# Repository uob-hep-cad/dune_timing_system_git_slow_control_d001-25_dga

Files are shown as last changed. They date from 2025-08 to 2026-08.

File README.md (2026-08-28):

# Design files for DUNE Timing System GIB Slow Control Board

### Current version: PCB_Health.v5 

### Files produced with KiCAD 10.0

Design information in hardware/KiCAD

David.Cussans@bristol.ac.uk , 9/June/26
 
Directory with Gerber artwork: Gerber.D001-25.DGA.V5 

Component placement (CSV and Gerber): PCB_Health.V5-all-pos.csv PCB_Health.V5-pnp_top.gbr PCB_Health.V5-pnp_bottom.gbr

BoM: PCB_Health.V5_BOM.xlsx . Version from Newbury: cleaned_full_bom_for_external_users.xlsx

4-layer board. FR4. 1.6mm  Newbury Electronics "PCB train" stack-up

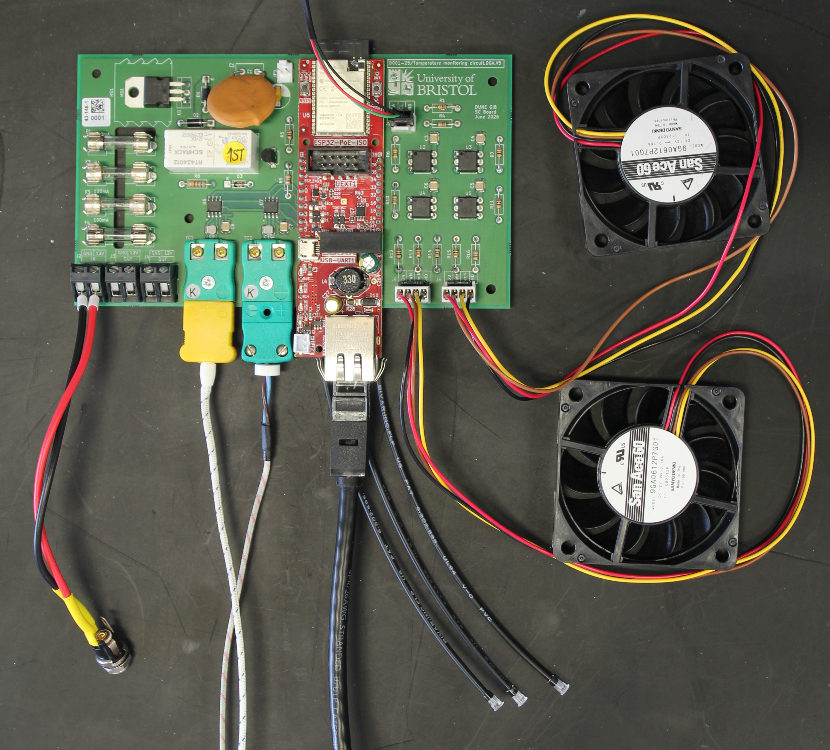
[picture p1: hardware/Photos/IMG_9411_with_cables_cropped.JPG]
photograph of assembled GIB slow control interface board
Photograph of assembled board:

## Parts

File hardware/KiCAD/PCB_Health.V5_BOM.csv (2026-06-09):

Reference | Qty | Value | DNP | Exclude from BOM | Exclude from Board | Footprint | Description | Datasheet
A1 | 1 | ESP32_POE |  |  |  | ESP32:ESP32-POE-ISO-WROVER | ESP32-POE-ISO-WROVER | https://cdn-learn.adafruit.com/downloads/pdf/adafruit-huzzah32-esp32-feather.pdf
C1 | 1 | 100n |  |  |  | Capacitor_THT:C_Disc_D9.0mm_W5.0mm_P5.00mm | Capacitor THT : C Disc D9.0mm W5.0mm P5.00mm 100n
C2 | 1 | 1u |  |  |  | Capacitor_THT:CP_Radial_D8.0mm_P5.00mm | Capacitor THT : CP Radial D8.0mm P5.00mm 1u
C3,C4,C5,C6,C7,C8 | 6 | 100n |  |  |  | Capacitor_SMD:C_1210_3225Metric | Capacitor SMD : C 1210 3225Metric 100n
C9,C10 | 2 | 10n |  |  |  | Capacitor_SMD:C_1210_3225Metric | Capacitor SMD : C 1210 3225Metric 10n
D1,D2 | 2 | 1N4001 |  |  |  | Diode_THT:D_DO-41_SOD81_P10.16mm_Horizontal | Diode THT : D DO-41 SOD81 P10.16mm Horizontal 1N4001 | http://www.vishay.com/docs/88503/1n4001.pdf
D3 | 1 | 1N4148 |  |  |  | Diode_THT:D_DO-35_SOD27_P7.62mm_Horizontal | Diode THT : D DO-35 SOD27 P7.62mm Horizontal 1N4148 | https://assets.nexperia.com/documents/data-sheet/1N4148_1N4448.pdf
D4,D5,D6 | 3 | LED |  |  |  | Library:FLPR60SG | FLPR60SG
F1 | 1 | 500mA |  |  |  | Library:Littelfuse 100 Spring Brass, PCB Fuse Clip for 5 x 20 mm Cartridge Fuse | Littelfuse 100 Spring Brass, PCB Fuse Clip for 5 x 20 mm Cartridge Fuse 500mA
F2 | 1 | 2A |  |  |  | Library:Littelfuse 100 Spring Brass, PCB Fuse Clip for 5 x 20 mm Cartridge Fuse | Littelfuse 100 Spring Brass, PCB Fuse Clip for 5 x 20 mm Cartridge Fuse 2A
F3,F4 | 2 | 100mA |  |  |  | Library:Littelfuse 100 Spring Brass, PCB Fuse Clip for 5 x 20 mm Cartridge Fuse | Littelfuse 100 Spring Brass, PCB Fuse Clip for 5 x 20 mm Cartridge Fuse 100mA
H1,H2,H4,H5 | 4 | MountingHole |  |  |  | MountingHole:MountingHole_3.2mm_M3 | MountingHole : MountingHole 3.2mm M3
HS1 | 1 | Heatsink |  |  |  | Heatsink:Heatsink_AAVID_TV5G_TO220_Horizontal | Heatsink : Heatsink AAVID TV5G TO220 Horizontal
J1 | 1 | Conn_01x03_Socket |  |  |  | Connector_PinHeader_2.54mm:PinHeader_1x03_P2.54mm_Vertical | Connector PinHeader 2.54mm : PinHeader 1x03 P2.54mm Vertical
J2,J3,J4 | 3 | Conn_01x02_Socket |  |  |  | TerminalBlock:TerminalBlock_Altech_AK300-2_P5.00mm | TerminalBlock : TerminalBlock Altech AK300-2 P5.00mm
J5 | 1 | Conn_01x04_Socket |  |  |  | Library:Mole_KK_1x04__Vertical | Molex KK 1x04 Vertical
J6 | 1 | Conn_01x04_Socket |  |  |  | Connector_PinHeader_2.54mm:PinHeader_1x04_P2.54mm_Vertical | Connector PinHeader 2.54mm : PinHeader 1x04 P2.54mm Vertical
JP1 | 1 | Jumper_2_Open |  |  |  | Connector_PinHeader_2.54mm:PinHeader_1x02_P2.54mm_Vertical | Connector PinHeader 2.54mm : PinHeader 1x02 P2.54mm Vertical
K1 | 1 | RT424012 |  |  |  | Relay_THT:Relay_DPDT_Schrack-RT2-FormC_RM5mm | Relay THT : Relay DPDT Schrack-RT2-FormC RM 5mm | http://www.te.com/commerce/DocumentDelivery/DDEController?Action=showdoc
Q1 | 1 | BC337 |  |  |  | Package_TO_SOT_THT:TO-92_Inline_Wide | Package TO SOT THT : TO-92 Inline Wide BC337 | https://diotec.com/tl_files/diotec/files/pdf/datasheets/bc337.pdf
R1,R4,R13,R15 | 4 | 10k |  |  |  | Library:R_Axial_DIN0207_L6.3mm_D2.5mm_P10.16mm_Horizontal | R Axial DIN0207 L6.3mm D2.5mm P10.16mm Horizontal 10k
R2 | 1 | 220 |  |  |  | Library:R_Axial_DIN0207_L6.3mm_D2.5mm_P10.16mm_Horizontal | R Axial DIN0207 L6.3mm D2.5mm P10.16mm Horizontal
R3 | 1 | 680 |  |  |  | Library:R_Axial_DIN0207_L6.3mm_D2.5mm_P10.16mm_Horizontal | R Axial DIN0207 L6.3mm D2.5mm P10.16mm Horizontal
R5,R7,R11,R12 | 4 | 270 |  |  |  | Library:R_Axial_DIN0207_L6.3mm_D2.5mm_P10.16mm_Horizontal | R Axial DIN0207 L6.3mm D2.5mm P10.16mm Horizontal
R6,R9,R10,R14,R16 | 5 | 470 |  |  |  | Library:R_Axial_DIN0207_L6.3mm_D2.5mm_P10.16mm_Horizontal | R Axial DIN0207 L6.3mm D2.5mm P10.16mm Horizontal
R8 | 1 | 620 |  |  |  | Library:R_Axial_DIN0207_L6.3mm_D2.5mm_P10.16mm_Horizontal | R Axial DIN0207 L6.3mm D2.5mm P10.16mm Horizontal
TC1,TC2 | 2 | Thermocouple_Alt |  |  |  | Connector Thermo:Thermocouple Connector | Connector Thermo : Thermocouple Connector
U1 | 1 | LM317_TO-220 |  |  |  | Package_TO_SOT_THT:TO-220-3_Vertical | Package TO SOT THT : TO-220-3 Vertical | http://www.ti.com/lit/ds/symlink/lm317.pdf
U2,U3,U4,U5 | 4 | H11L1 |  |  |  | Library:DIP-6_W7.62mm | DIP-6 W7.62mm | https://www.onsemi.com/pub/Collateral/H11L3M-D.PDF
U6,U7 | 2 | MAX6675ISA_ |  |  |  | MAX6675ISA_:SOIC127P600X175-8N | MAX6675ISA : SOIC127P600X175-8N

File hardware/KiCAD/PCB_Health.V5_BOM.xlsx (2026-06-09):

Description | Qty per BOM | Quantity per batch | Min Quantity to order | Manufacturer | Manufacturer Part Number | Supplier | Supplier Part Number | Designator | Package Type | Technology | Comment | Status | Original Manufacturer Part No from client BOM
ESP32-POE IOT EVAL BOARD | 1 | 2 | 2 | Olimex LTD | ESP32-POE-ISO-WROVER | DIGIKEY | 1188-ESP32-POE-ISO-WROVER-ND | A1 | Bulk | THT |  | Found | ESP32_POE
CAP CER 0.1UF 500V Z5V RADIAL | 7 | 14 | 14 | Vishay Beyschlag/Draloric/BC Components | S104Z93Z5VL83L0R | DIGIKEY | BC5183-ND | C1,C3,C4,C5,C6,C7,C8 | Bulk | THT |  | Found | 100n
CAP TANT 1UF 10% 25V RADIAL | 1 | 2 | 2 | KEMET | T356A105K025AT | DIGIKEY | 399-3603-ND | C2 | Bulk | THT |  | Found | 1u
YAGEO - CC1210FKNPO9BN103 - SMD Multilayer Ceramic Capacitor, 0.01 µF, 50 V, 1210 [3225 Metric], ± 1%, C0G / NP0 | 2 | 4 | 5 | YAGEO | CC1210FKNPO9BN103 | FARNELL | 4255887 | C9,C10 | Cut Tape | SMD |  | Found | 10n
MULTICOMP PRO - 1N4001. - DIODE, STANDARD RECOVERY, 1A, 50V, DO-204AL-2 | 2 | 4 | 5 | MULTICOMP PRO | 1N4001. | FARNELL | 2306346 | D1,D2 | Cut Tape | THT |  | Found | 1N4001
MULTICOMP PRO - 1N4148. - DIODE, ULTRAFAST RECOVERY, 150mA, 75V, DO-204AH-2 | 1 | 2 | 5 | MULTICOMP PRO | 1N4148. | FARNELL | 2306361 | D3 | Cut Tape | THT |  | Found | 1N4148
LED CBI 3MM GRN THROUGH HOLE | 3 | 6 | 6 | Bivar Inc. | FLPR6.0-SG | DIGIKEY | 492-1201-ND | D4,D5,D6 | Bag | THT |  | Found | LED
FUSE CLIP CARTRIDGE 250V 10A PCB | 1 | 2 | 2 | Littelfuse Inc. | 01000056Z | DIGIKEY | F3784-ND | F1 | Bulk | THT |  | Found | 500mA
FUSE CLIP CARTRIDGE 250V 10A PCB | 1 | 2 | 2 | Littelfuse Inc. | 01000056Z | DIGIKEY | F3784-ND | F2 | Bulk | THT |  | Found | 2A
FUSE CLIP CARTRIDGE 250V 10A PCB | 2 | 4 | 4 | Littelfuse Inc. | 01000056Z | DIGIKEY | F3784-ND | F3,F4 | Bulk | THT |  | Found | 100mA
BOYD - TV5G - Heat Sink, PCB, Board Level, 21.6 °C/W, TO-126, 22 mm, 19 mm, 19 mm | 1 | 2 | 2 | BOYD | TV5G | FARNELL | 170072 | HS1 | Each | UNMOUNTED |  | Found | Heatsink
Headers & Wire Housings 3C STR HEADER W/FRLK | 1 | 2 | 2 | Molex | 22-27-2031 | MOUSER | 538-22-27-2031 | J1 | Standard Pack Qty | THT |  | Found | Conn_01x03_Socket
Fixed Terminal Blocks AK300/2 PC 45DegGry | 3 | 6 | 6 | Altech | 30.602 | MOUSER | 845-30.602 | J2,J3,J4 | Standard Pack Qty | THT |  | Found | Conn_01x02_Socket
MOLEX - 171856-4004 - Pin Header, Black, Board-to-Board, Power, Signal, Wire-to-Board, 2.54 mm, 1 Rows, 4 Contacts | 2 | 4 | 4 | MOLEX | 171856-4004 | FARNELL | 4667772 | J5,J6 | Cut Tape | THT |  | Found | Conn_01x04_Socket
Conn Wire to Board HDR 2 POS 2.54mm Solder ST Top Entry Thru-Hole KK Bag | 1 | 2 | 2 | Molex | 0022232021 | ARROW | 0323_00039992 | JP1 | BAG | THT |  | Found | Jumper_2_Open
Power Relay 12VDC 8A DPDT(29x12.7x15.7)mm THT | 1 | 2 | 2 | TE Connectivity | RT424012 | ARROW | 0323_00028596 | K1 | BOX | THT |  | Found | RT424012
MULTICOMP PRO - BC337 - Bipolar (BJT) Single Transistor, NPN, 45 V, 800 mA, 625 mW, TO-92, Through Hole | 1 | 2 | 5 | MULTICOMP PRO | BC337 | FARNELL | 1574379 | Q1 | Each | THT |  | Found | BC337
MULTICOMP PRO - MCRE000049 - Through Hole Resistor, 10 kohm, MC CFR Series, 125 mW, ± 5%, Axial Leaded, 200 V | 4 | 8 | 8 | MULTICOMP PRO | MCRE000049 | FARNELL | 1700251 | R1,R4,R13,R15 | Each | THT |  | Found | 10k
MULTICOMP PRO - MCRE000029 - Through Hole Resistor, 220 ohm, MC CFR Series, 125 mW, ± 5%, Axial Leaded, 200 V | 1 | 2 | 5 | MULTICOMP PRO | MCRE000029 | FARNELL | 1700228 | R2 | Each | THT |  | Found | 220
MULTICOMP PRO - MCRE000035 - Through Hole Resistor, 680 ohm, MC CFR Series, 125 mW, ± 5%, Axial Leaded, 200 V | 1 | 2 | 5 | MULTICOMP PRO | MCRE000035 | FARNELL | 1700234 | R3 | Each | THT |  | Found | 680
MULTICOMP PRO - MCRE000030 - Through Hole Resistor, 270 ohm, MC CFR Series, 125 mW, ± 5%, Axial Leaded, 200 V | 4 | 8 | 8 | MULTICOMP PRO | MCRE000030 | FARNELL | 1700229 | R5,R7,R11,R12 | Each | THT |  | Found | 270
MULTICOMP PRO - MCRE000033 - Through Hole Resistor, 470 ohm, MC CFR Series, 125 mW, ± 5%, Axial Leaded, 200 V | 5 | 10 | 10 | MULTICOMP PRO | MCRE000033 | FARNELL | 1700232 | R6,R9,R10,R14,R16 | Each | THT |  | Found | 470
RES 620 OHM 5% 1/4W AXIAL | 1 | 2 | 2 | KOA Speer Electronics, Inc. | CF1/4CT52R621J | DIGIKEY | 2019-CF1/4CT52R621JCT-ND | R8 | Cut Tape (CT) | THT |  | Found | 620
LABFACILITY - IM-K-PCB - Thermocouple Connector, Miniature, Green, Socket, Type K, IEC, PCB Mount | 2 | 4 | 4 | LABFACILITY | IM-K-PCB | FARNELL | 3810628 | TC1,TC2 | Each | THT |  | Found | Thermocouple_Alt
Standard Regulator Pos 1.2V to 37V 0.4A 3-Pin(3+Tab) TO-220AB Tube | 1 | 2 | 2 | STMicroelectronics | LM317T | ARROW | 0323_00031097 | U1 | RAIL | THT |  | Found | LM317_TO-220
Optocoupler Logic-Out DC-IN 1-CH 6-Pin DIP | 4 | 8 | 8 | Everlight Electronics | H11L1 | ARROW | 0323_02418914 | U2,U3,U4,U5 | BULK | THT |  | Found | H11L1
ANALOG DEVICES - MAX6675ISA+ - Temperature Sensor IC, Digital, ± 3°C, 0 °C, 1024 °C, NSOIC, 8 Pins | 2 | 4 | 4 | ANALOG DEVICES | MAX6675ISA+ | FARNELL | 2518704 | U6,U7 | Each | SMD |  | Found | MAX6675ISA_

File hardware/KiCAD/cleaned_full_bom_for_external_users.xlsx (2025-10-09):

Description | Qty per BOM | Quantity per batch | Min Quantity to order | Manufacturer | Manufacturer Part Number | Supplier | Supplier Part Number | Designator | Package Type | Technology | Comment | Status | Original Manufacturer Part No from client BOM
WiFi Development Tools - 802.11 ESP32-POE-ISO IoT development board with 100Mb Ethernet, Power over Ethernet, WiFi, BLE, programmer | 1 | 2 | 2 | Olimex Ltd. | ESP32-POE-ISO-WROVER | MOUSER | 909-P32POEISOWROVER | A1 | Standard Pack Qty | THT | ESP32_POE | Found | ESP32-POE-ISO-WROVER
Multilayer Ceramic Capacitors MLCC - SMD/SMT WCAP-CSGP 0.01uF 1210 5% 50V MLCC | 2 | 4 | 4 | Wurth Elektronik | 885012009023 | MOUSER | 710-885012009023 | C1,C2 | Cut Tape | SMD | 10n | Found | 885012009023
CAP CER 0.1UF 50V X7R 0805 | 7 | 14 | 14 | KEMET | C0805C104K5RACTU | DIGIKEY | 399-C0805C104K5RACTUCT-ND | C3,C4,C5,C6,C7,C8,C9 | Cut Tape (CT) | SMD | 100n | Found | C0805C104K5RACTU
Aluminium Electrolytic Capacitors - Radial Leaded 1.0UF 250V ELECT NHG RADIAL | 1 | 2 | 2 | Panasonic | ECA-2EHG010 | MOUSER | 667-ECA-2EHG010 | C10 | Standard Pack Qty | SMD | 1u | Found | ECA2EHG010
MULTICOMP PRO - 1N4001. - DIODE, STANDARD RECOVERY, 1A, 50V, DO-204AL-2 | 2 | 4 | 5 | MULTICOMP PRO | 1N4001. | FARNELL | 2306346 | D1,D2 | Cut Tape | THT | 1N4001 | Found | 1N4001-E3/54
PCB MNT FUSEHOLDER 5X20MM | 4 | 8 | 8 | BULGIN LTD | FX0457 | ANGLIA | 138857001 | F1,F2,F3,F4 | Bag | SMD | 500mA | Found | FX0457
Screws & Fasteners PEEK SOCKET HEAD SCREW M3 X 10 | 1 | 2 | 2 | Essentra | 183031070409 | MOUSER | 144-183031070409 | H1 | Standard Pack Qty | UNMOUNTED | Heatsink fixing | Found
BOYD - TV5G - Heat Sink, PCB, Board Level, 21.6 °C/W, TO-126, 22 mm, 19 mm, 19 mm | 1 | 2 | 2 | BOYD | TV5G | FARNELL | 170072 | HS1 | Each | SMD | Heatsink | Found | TV5G
TERMINAL BLOCK 2W | 3 | 6 | 6 | CAMDENBOSS | CTB0502/2 | ANGLIA | 1041430001 | J1,J2,J5 | Bag | THT | Conn_01x02_Socket | Found | 897-0843
Conn Wire to Board HDR 4 POS 2.54mm Solder ST Top Entry Thru-Hole KK Bag | 2 | 4 | 4 | Molex | 0022292041 | ARROW | 0323_00030517 | J3,J4 | BAG | THT | Conn_01x04_Socket | Found | 22-29-2041
Conn Wire to Board HDR 3 POS 2.54mm Solder ST Top Entry Thru-Hole KK Bag | 1 | 2 | 2 | Molex | 0022272031 | ARROW | 0323_00036827 | J6 | BAG | THT | Conn_01x03_Pin | Found | 22-27-2031
Relay: electromagnetic; DPDT; Ucoil: 12VDC; 8A; 8A/250VAC; 8A/30VDC | 1 | 2 | 2 | TE Connectivity | RT424012 | TME | RT424012 | K1 |  | THT | RT424012 | Found | RT424012
TO92 45V 0.8A 0.625W NPN | 1 | 2 | 1000 | INVAC | BC337-25 | ANGLIA | 1517347001 | Q1 | Bag | THT | BC337 | Found | BC337-25 A1
Metal Film Resistors - Through Hole 470 OHM 1/4W 1% | 5 | 10 | 10 | YAGEO | MFR-25FTE52-470R | MOUSER | 603-MFR-25FTE52-470R | R1,R3,R5,R7,R8 | Standard Pack Qty | THT | 470 | Found | MFR-25FTE52-470R
RES 270 OHM 1% 1/4W AXIAL | 4 | 8 | 8 | YAGEO | MFR-25FTE52-270R | DIGIKEY | 13-MFR-25FTE52-270RCT-ND | R2,R4,R6,R9 | Cut Tape (CT) | THT | 270 | Found | MFR-25FTE52-270R
RES 680 OHM 1% 0.6W AXIAL | 1 | 2 | 2 | TE Connectivity Passive Product | LR1F680R | DIGIKEY | A105963CT-ND | R11 | Cut Tape (CT) | SMD | 680 | Found | LR1F680R
IEC TYPE K PCB SOCKET IM-K-PCB | 2 | 4 | 4 | Labfacility Ltd | XE-1109-001 | DIGIKEY | 5425-XE-1109-001-ND | TC1,TC2 | Bag | THT | Thermocouple_Alt | Found | 304-14-320
Optocoupler Logic-Out DC-IN 1-CH 6-Pin DIP | 4 | 8 | 8 | Everlight Electronics | H11L1 | ARROW | 0323_02418914 | U1,U4,U5,U7 | BULK | SMD | H11L1 | Found | H11L1
ANALOG DEVICES - MAX6675ISA+ - Temperature Sensor IC, Digital, ± 3°C, 0 °C, 1024 °C, NSOIC, 8 Pins | 2 | 4 | 4 | ANALOG DEVICES | MAX6675ISA+ | FARNELL | 2518704 | U2,U3 | Each | SMD | MAX6675ISA_ | Found | MAX6675ISA+
IC: voltage regulator; linear,adjustable; 1.2÷37V; 1.5A; TO220-3 | 1 | 2 | 2 | TEXAS INSTRUMENTS | LM317T/NOPB | TME | LM317T/NOPB | U6 |  | THT | LM317_TO-220 | Found | LM317T/NOPB
RES 220 OHM 1% 1/4W AXIAL | 1 | 2 | 2 | YAGEO | MFR-25FTE52-220R | DIGIKEY | 13-MFR-25FTE52-220RCT-ND | R10 | Cut Tape (CT) | THT |  | Found

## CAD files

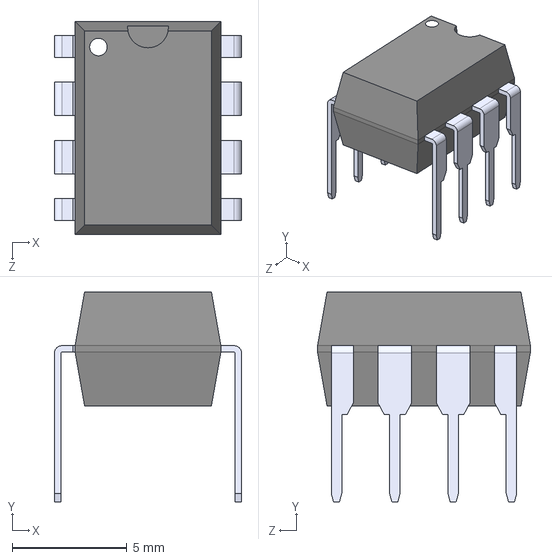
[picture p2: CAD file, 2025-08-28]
hardware/KiCAD/LT1025CN8_PBF/LT1025CN8_PBF.step
8.15 x 9.14 x 9.27 mm

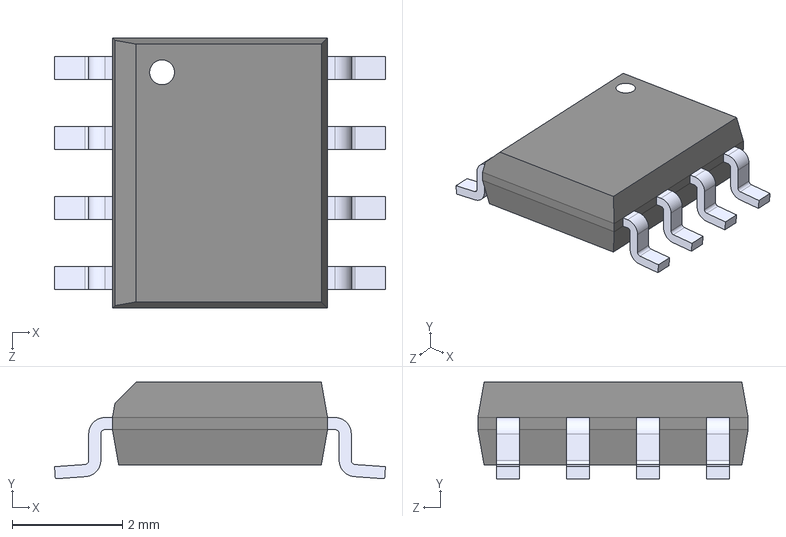
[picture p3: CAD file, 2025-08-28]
hardware/KiCAD/MAX6675ISA_/MAX6675ISA_.step
6.00 x 1.75 x 4.90 mm

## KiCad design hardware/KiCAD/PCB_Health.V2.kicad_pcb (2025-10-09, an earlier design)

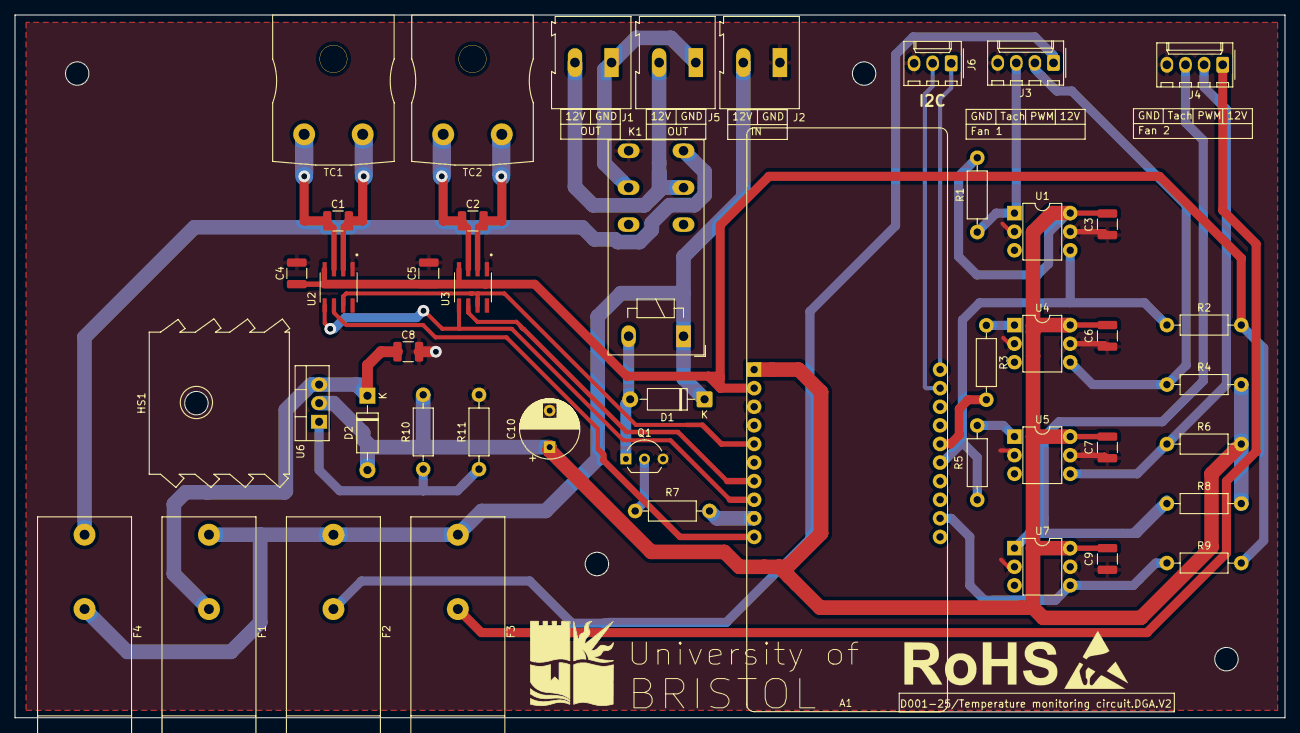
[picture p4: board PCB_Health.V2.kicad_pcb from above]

Board: 4 copper layers, 173.5 x 96.0 mm, 51 parts (0 on the bottom side), 33 nets.

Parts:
A1: ESP32_POE; ESP32-POE-ISO-WROVER
C1, C2: 10n; C_1210_3225Metric
C3, C4, C5, C6, C7, C8, C9: 100n; C_1210_3225Metric
C10: 1u; CP_Radial_D8.0mm_P5.00mm
D1, D2: 1N4001; D_DO-41_SOD81_P10.16mm_Horizontal
F1: 500mA; Fuseholder_Cylinder-5x20mm_Bulgin_FX0457_Horizontal_Closed
F2, F3: 100mA; Fuseholder_Cylinder-5x20mm_Bulgin_FX0457_Horizontal_Closed
F4: 3A; Fuseholder_Cylinder-5x20mm_Bulgin_FX0457_Horizontal_Closed
H1, H1#2, H2, H3, H4: MountingHole; MountingHole_3.2mm_M3
HS1: Heatsink; Heatsink_AAVID_TV5G_TO220_Horizontal
J1, J2, J5: Conn_01x02_Socket; TerminalBlock_Altech_AK300-2_P5.00mm
J3, J4: Conn_01x04_Socket; Molex_KK-254_AE-6410-04A_1x04_P2.54mm_Vertical
J6: Conn_01x03_Pin; Molex_KK-254_AE-6410-03A_1x03_P2.54mm_Vertical
K1: RT424012; Relay_DPDT_Schrack-RT2-FormC_RM5mm
Q1: BC337; TO-92_Inline_Wide
R1, R3, R5, R7, R8: 470; R_Axial_DIN0207_L6.3mm_D2.5mm_P10.16mm_Horizontal
R2, R4, R6, R9: 270; R_Axial_DIN0207_L6.3mm_D2.5mm_P10.16mm_Horizontal
R10: 220; R_Axial_DIN0207_L6.3mm_D2.5mm_P10.16mm_Horizontal
R11: 680; R_Axial_DIN0207_L6.3mm_D2.5mm_P10.16mm_Horizontal
TC1, TC2: Thermocouple_Alt; Thermocouple Connector
U1, U4, U5, U7: H11L1; DIP-6_W7.62mm
U2, U3: MAX6675ISA_; SOIC127P600X175-8N
U6: LM317_TO-220; TO-220-3_Vertical

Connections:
+3.3V: A1.2 (3V3), C4.1, C5.1, R2.2, R9.2, U2.4 (VCC), U3.4 (VCC)
+5V: A1.1 (+5V), C3.1, C6.1, C7.1, C9.1, C10.1, D2.2 (A), R1.2, R4.2, R6.2, R8.2, R10.2, U1.6, U4.6, U5.6, U6.2 (VO), U7.6
+12V: D1.1 (K), F1.1, F2.1, F3.1, F4.2, J2.2, K1.A1
/GPIO0: A1.5 (GPIO0), U2.7 (SO), U3.7 (SO)
/GPIO2: A1.7 (GPIO2), U3.6 (~CS)
/GPIO3: A1.8 (GPIO3), U2.5 (SCK), U3.5 (SCK)
/GPIO4: A1.9 (GPIO4), R7.1
/GPIO5: A1.10 (GPIO5), U2.6 (~CS)
/GPIO14: A1.12 (GPIO14), R9.1, U7.4
/GPIO32: A1.15 (GPIO32), R2.1, R5.2, U1.4
/GPIO33: A1.16 (GPIO33), R3.2
/GPIO36: A1.19 (GPIO36), J6.2
/GPIO39: A1.20 (GPIO39), J6.1
GND: A1.3 (GND), C3.2, C4.2, C5.2, C6.2, C7.2, C8.2, C9.2, C10.2, J2.1, J3.4, J4.4, J6.3, K1.24, Q1.3 (E), R11.2, U1.2, U1.5, U2.1 (GND), U3.1 (GND), U4.2, U4.5, U5.2, U5.5, U7.2, U7.5
unnamed: D1.2 (A), K1.A2, Q1.1 (C)
unnamed: C8.1, D2.1 (K), F1.2, U6.3 (VI)
unnamed: F4.1, K1.14
unnamed: J1.1, J5.1, K1.21
unnamed: J1.2, J5.2, K1.11
unnamed: F2.2, J3.1
unnamed: J3.2, R4.1, U4.4
unnamed: J3.3, R1.1, U1.1
unnamed: F3.2, J4.1
unnamed: J4.2, R6.1, U5.4
unnamed: J4.3, R8.1, U7.1
unnamed: Q1.2 (B), R7.2
unnamed: R3.1, U4.1
unnamed: R5.1, U5.1
unnamed: C1.1, TC1.1 (+), U2.3 (T+)
unnamed: C1.2, TC1.2 (-), U2.2 (T-)
unnamed: C2.1, TC2.1 (+), U3.3 (T+)
unnamed: C2.2, TC2.2 (-), U3.2 (T-)
unnamed: R10.1, R11.1, U6.1 (ADJ)

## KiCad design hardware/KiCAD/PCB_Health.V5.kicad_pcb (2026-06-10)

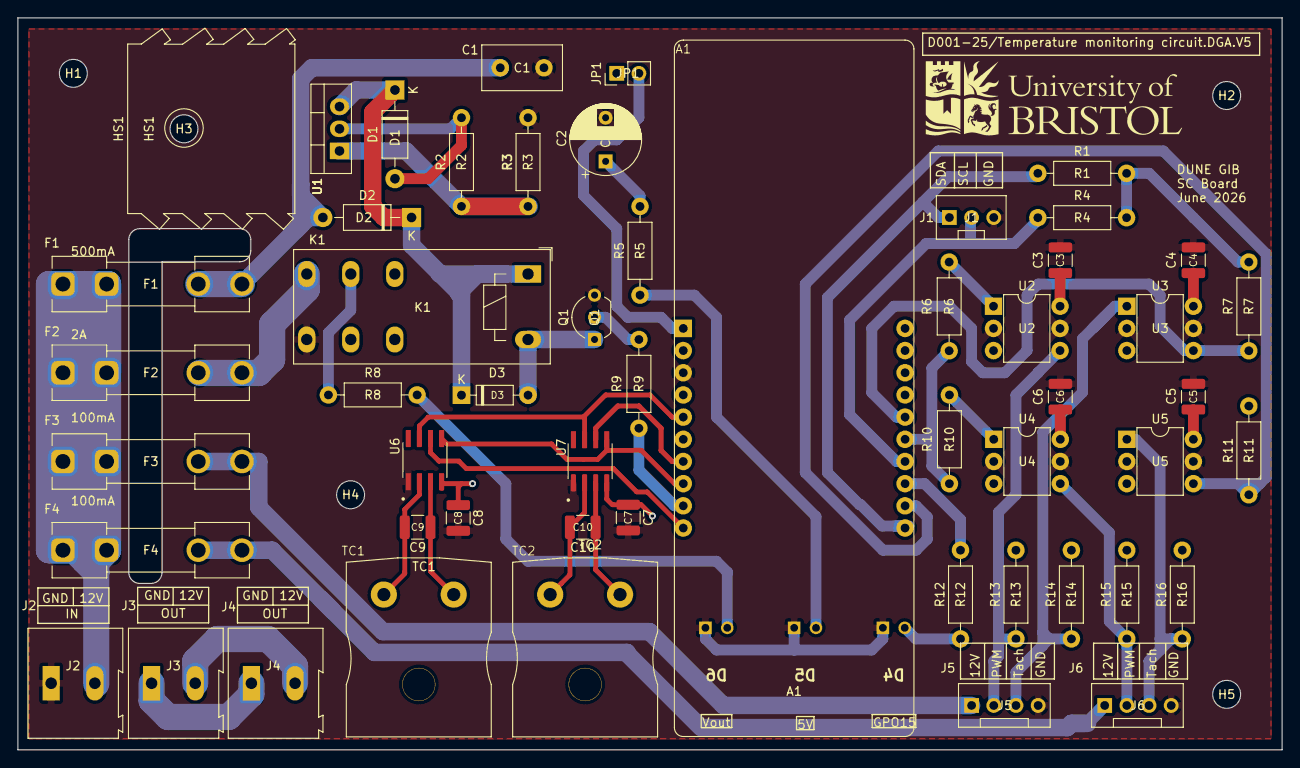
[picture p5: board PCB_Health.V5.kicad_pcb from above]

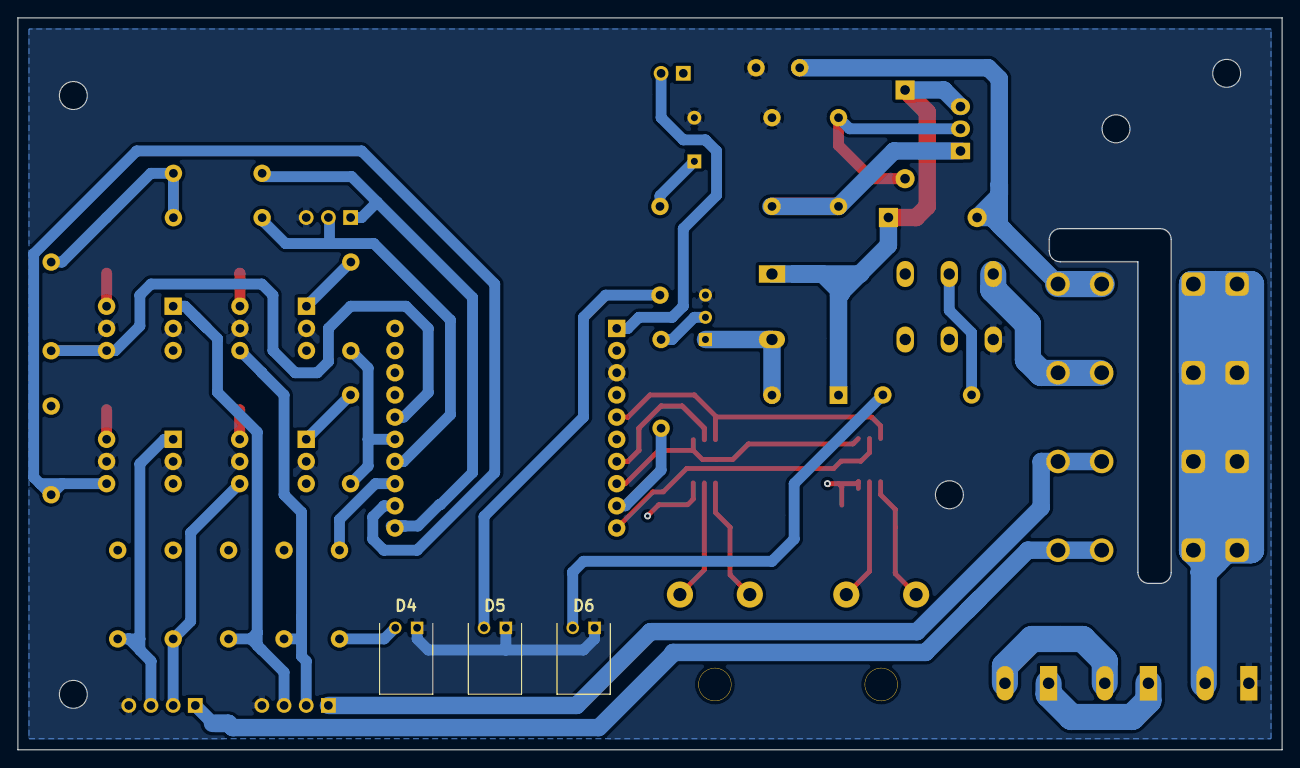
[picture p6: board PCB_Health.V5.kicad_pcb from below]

Board: 4 copper layers, 144.8 x 83.8 mm, 61 parts (3 on the bottom side), 39 nets.

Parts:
A1: ESP32_POE; ESP32-POE-ISO-WROVER
C1: 100n; C_Disc_D9.0mm_W5.0mm_P5.00mm
C2: 1u; CP_Radial_D8.0mm_P5.00mm
C3, C4, C5, C6, C7, C8: 100n; C_1210_3225Metric
C9, C10: 10n; C_1210_3225Metric
D1, D2: 1N4001; D_DO-41_SOD81_P10.16mm_Horizontal
D3: 1N4148; D_DO-35_SOD27_P7.62mm_Horizontal
D4, D5, D6: LED; FLPR60SG
F1: 500mA; Littelfuse 100 Spring Brass, PCB Fuse Clip for 5 x 20 mm Ca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
F2: 2A; Littelfuse 100 Spring Brass, PCB Fuse Clip for 5 x 20 mm Ca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
F3, F4: 100mA; Littelfuse 100 Spring Brass, PCB Fuse Clip for 5 x 20 mm Ca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
H1, H2, H3, H4, H5: MountingHole; MountingHole_3.2mm_M3
HS1: Heatsink; Heatsink_AAVID_TV5G_TO220_Horizontal
J1: Conn_01x03_Socket; PinHeader_1x03_P2.54mm_Vertical
J2, J3, J4: Conn_01x02_Socket; TerminalBlock_Altech_AK300-2_P5.00mm
J5: Conn_01x04_Socket; Mole_KK_1x04__Vertical
J6: Conn_01x04_Socket; PinHeader_1x04_P2.54mm_Vertical
JP1: Jumper_2_Open; PinHeader_1x02_P2.54mm_Vertical
K1: RT424012; Relay_DPDT_Schrack-RT2-FormC_RM5mm
Q1: BC337; TO-92_Inline_Wide
R1, R4, R13, R15: 10k; R_Axial_DIN0207_L6.3mm_D2.5mm_P10.16mm_Horizontal
R2: 220; R_Axial_DIN0207_L6.3mm_D2.5mm_P10.16mm_Horizontal
R3: 680; R_Axial_DIN0207_L6.3mm_D2.5mm_P10.16mm_Horizontal
R5, R7, R11, R12: 270; R_Axial_DIN0207_L6.3mm_D2.5mm_P10.16mm_Horizontal
R6, R9, R10, R14, R16: 470; R_Axial_DIN0207_L6.3mm_D2.5mm_P10.16mm_Horizontal
R8: 620; R_Axial_DIN0207_L6.3mm_D2.5mm_P10.16mm_Horizontal
TC1, TC2: Thermocouple_Alt; Thermocouple Connector
U1: LM317_TO-220; TO-220-3_Vertical
U2, U3, U4, U5: H11L1; DIP-6_W7.62mm
U6, U7: MAX6675ISA_; SOIC127P600X175-8N

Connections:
+3.3V: A1.2 (3V3), C7.1, C8.1, R1.1, R4.1, R7.2, R11.2, U6.4 (VCC), U7.4 (VCC)
+5V: C2.1, C3.1, C4.1, C5.1, C6.1, D1.2 (A), JP1.1 (A), R2.2, R5.2, R13.2, R14.2, R15.2, R16.2, U1.2 (VO), U2.6, U3.6, U4.6, U5.6
+12V: F1.1, F2.1, F3.1, F4.1, J2.2
/12: D1.1 (K), D2.1 (K), D3.1 (K), K1.A1, U1.3 (VI)
/GPIO0: A1.5 (GPIO0), U6.7 (SO), U7.7 (SO)
/GPIO2: A1.7 (GPIO2), U7.6 (~CS)
/GPIO3: A1.8 (GPIO3), U6.5 (SCK), U7.5 (SCK)
/GPIO4: A1.9 (GPIO4), R9.1
/GPIO5: A1.10 (GPIO5), U6.6 (~CS)
/GPIO13: A1.11 (GPIO13), J1.1, R1.2
/GPIO14: A1.12 (GPIO14), R11.1, U5.4
/GPIO15: A1.13 (GPIO15), R12.2
/GPIO16: A1.14 (GPIO16), J1.2, R4.2
/GPIO32: A1.15 (GPIO32), R6.2, R10.2
/GPIO33: A1.16 (GPIO33), R7.1, U3.4
/Vout: J3.2, J4.2, K1.11, R8.2
GND: A1.3 (GND), C1.2, C2.2, C3.2, C4.2, C5.2, C6.2, C7.2, C8.2, D4.1 (K), D5.1 (K), D6.1 (K), J1.3, J2.1, J5.4, J6.4, K1.24, Q1.3 (E), R3.2, U2.2, U2.5, U3.2, U3.5, U4.2, U4.5, U5.2, U5.5, U6.1 (GND), U7.1 (GND)
unnamed: A1.1 (+5V), JP1.2 (B)
unnamed: D3.2 (A), K1.A2, Q1.1 (C)
unnamed: D6.2 (A), R8.1
unnamed: D5.2 (A), R5.1
unnamed: D4.2 (A), R12.1
unnamed: C1.1, D2.2 (A), F1.2
unnamed: F2.2, K1.14
unnamed: J3.1, J4.1, K1.21
unnamed: F3.2, J5.1
unnamed: J5.2, R13.1, U2.4
unnamed: J5.3, R14.1, U3.1
unnamed: F4.2, J6.1
unnamed: J6.2, R15.1, U4.4
unnamed: J6.3, R16.1, U5.1
unnamed: Q1.2 (B), R9.2
unnamed: R6.1, U2.1
unnamed: R10.1, U4.1
unnamed: C9.1, TC1.1 (+), U6.3 (T+)
unnamed: C9.2, TC1.2 (-), U6.2 (T-)
unnamed: C10.1, TC2.1 (+), U7.3 (T+)
unnamed: C10.2, TC2.2 (-), U7.2 (T-)
unnamed: R2.1, R3.1, U1.1 (ADJ)

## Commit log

2025-08-28 Adding KiCAD files for PCB_Health board for GIB. Adding README
    [LT1025CN8_PBF.step, MAX6675ISA_.step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]
2025-10-08 Added v2 files
    [PCB_Health.V2-B_Cu.gbr, PCB_Health.V2-B_Mask.gbr, PCB_Health.V2-B_Paste.gbr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]
2025-10-09 Creating Fab and assy outputs for PCB_Health board
    [PCB_Health.V2-B_Cu.gbr, PCB_Health.V2-B_Mask.gbr, PCB_Health.V2-B_Paste.gbr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]
2025-10-09 Regenerated artwork (one last time?). Deleted obsolete mfr files. Added cleaned_full_bom_for_external_users.xlsx, the BoM generated by Newbury
    [PCB_Health.V2-B_Cu.gbr, PCB_Health.V2-B_Mask.gbr, PCB_Health.V2-B_Paste.gbr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]
2026-01-20 Pushing changes before switching back to GIB main PCB branch
2026-05-11 Updated design to V4 ( KiCAD project = PCB_Health.V4.kicad_pro
    [PCB_Health.V4.kicad_pcb, PCB_Health.V4.kicad_sch]
2026-06-09 Adding files updated by David G.A.
    [PCB_Health.V5-B_Cu.gbr, PCB_Health.V5-B_Mask.gbr, PCB_Health.V5-B_Paste.gbr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]
2026-06-09 Tidied up BoM using Newbury online tool
    [PCB_Health.V5.csv, PCB_Health.V5.kicad_pcb, PCB_Health.V5_BOM.csv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]
2026-06-09 Created a Zip archive with Gerbers, drill files, BoM and README
2026-06-10 Fiddled with silk screen - changed v4 to v5
    [PCB_Health.V5.kicad_pcb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]
2026-08-26 Adding Gerbers for pre-production board. Adding photos of pre-production board
    [PCB_Health.V5-F_Silkscreen.gbr, PCB_Health.V5-job.gbrjob]
2026-08-28 Adding photos of slow control board
2026-08-28 Adding BoM for GIB slow control board
    [PCB_Health.V5-01.csv]
2026-08-28 Cleaning up directory structure
    [PCB_Health.V2.csv, PCB_Health.V2.kicad_pcb, PCB_Health.V2.kicad_sch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]
2026-08-28 Adding local symbols and Gerber from earlier versions of the board
    [LT1025CN8_PBF.step, MAX6675ISA_.step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]
